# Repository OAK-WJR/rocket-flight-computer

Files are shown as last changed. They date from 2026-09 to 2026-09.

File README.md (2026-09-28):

# Rocket Flight Computer (M3 single board)

Flight computer for an amateur high-power rocket: 2S LiPo, STM32H743VIT6, IMU (ICM-45686), barometer (MS5611), GNSS (SAM-M10Q), QSPI flight log, USB and a RunCam camera interface. The goal is **one 46 mm-wide, four-layer board that fits a 54.66 mm ID airframe**, including dual pyro channels and four-servo roll control.

> **Current status: M3-ASSY-R2 is the complete-function CAD candidate, not flight hardware.** Power / MCU / sensors / logging / USB / GNSS / camera **plus** the actuator switch, four servos, two independently fused pyro channels with a complete arming break, pull-pin and buzzer are routed on one 46 × 238 mm four-layer board. DRC, ERC and schematic parity are zero, every part was checked against its datasheet ([docs/R2_VERIFICATION.md](docs/R2_VERIFICATION.md)) and the actuator band is simulated ([m3_design/sim_r2](m3_design/sim_r2/FINDINGS.md)). Nothing has been built or measured, and R2 firmware does not exist yet. Full requirements and gaps: [STATUS.md](STATUS.md).

## Layout

| Path | Contents |
|---|---|
| `m3_design/assembly_review/` | **The current KiCad project (the single source of truth)**: `m3.kicad_pro`, fourteen schematic sheets, PCB, project-local footprints, symbols and 3D models, and the review notes `ASSEMBLY_REVIEW.md` |
| `m3_design/sim_r2/` | ngspice suite for the R2 actuator band (`run.py`, `RESULTS.md`, `FINDINGS.md`) |
| `reference/` | `m1_power_actuator/`: the legacy M1 actuator board R2 was merged from; `m3_assy_r1/`: the R1 board the v0.8.1 firmware and `diagnostics/` are still bound to |
| `docs/` | Ordering guide (`ORDERING.md`), verification record (`R2_VERIFICATION.md`), actuator merge record (`M3_ACTUATOR_MERGE.md`), design rationale: frozen design and BOM, circuit review, FMEA, margin prescription, airframe geometry, automated test design, simulation, design history |
| `m3_firmware/` | Bench diagnostic firmware v0.8.1 source, binding / protocol definitions and tests; `build_assembly_*/` holds prebuilt images **for R1 only — do not run them on R2** |
| `diagnostics/` | Host-side diagnostic and fault-localisation tools (USB, SWD, log recovery, test-point map) |
| `quality_audit/` | Board-level audit: metadata conflicts, 3D model paths, DRC / ERC evidence |
| `tools/check.sh` | One-command board gate |

## Quick start

Requires **KiCad 10.0.x** (file format 20260206; older versions cannot open it) and Python 3.9+.

```bash
tools/check.sh                                     # DRC + ERC + parity + metadata/3D audit; passes only at zero
python3 m3_design/check_actuators.py               # pyro / arming / servo safety contract
python3 m3_design/sim_r2/run.py                    # SPICE suite (needs ngspice)
open m3_design/assembly_review/m3.kicad_pro        # open in KiCad
pip install -r diagnostics/requirements-lock.txt   # host diagnostic dependencies (pyocd etc.)
python3 -m unittest discover -s diagnostics -t . -p 'test_*.py'
(cd m3_firmware && PYTHONPATH=.. python3 -m unittest test_firmware test_gnss test_usb)
```

Building the firmware needs the ARM GNU Toolchain 15.2.rel1 unpacked into `m3_firmware/toolchain/` (see the `TOOL` path at the top of `m3_firmware/build.py`). **After any PCB change, `build.py` refuses to build until the pin binding has been reviewed again** — this is intentional.

## Collaboration

See [AGENTS.md](AGENTS.md): development rules, safety constraints, what remains for the complete PCB, and the contribution workflow.

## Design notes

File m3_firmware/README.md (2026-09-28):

# M3 bench diagnostic firmware

> **M3-ASSY-R2 (actuator merge, 2026-09-25): no firmware exists for R2 yet.** R2 moves LED_RED from PE3 to PE8 and turns PE3 / PE6 into no-net sentinels beside the pyro gates PE4 / PE5, so **v0.8.1 must not be run on an R2 board** (it drives PE3). `build.py` already refuses to build against the changed PCB hash; the reviewed R2 GPIO roles are in [`pins_r2.json`](pins_r2.json) and the rules in [`../docs/M3_ACTUATOR_MERGE.md`](../docs/M3_ACTUATOR_MERGE.md). A new binding must be written from `assembly_binding.py` together with the first R2 firmware, not by editing the R1 hash. The R2 hardware also relies on two firmware rules (`docs/M3_ACTUATOR_MERGE.md` §2.6): every pyro fire pulse ends after 20 ms, and flight state survives an MCU reset so channel 2 still fires. Full list: `docs/R2_VERIFICATION.md` §5 (includes reading VLOGIC_SENSE / V3V3_SENSE on ADC3 and keeping U3 a W25Q128JV-IQ).

**Current version: v0.8.1 for M3-ASSY-R1.** Usage: [ASSEMBLY_DIAGNOSTICS.md](ASSEMBLY_DIAGNOSTICS.md). The host-side [triage entry point](../diagnostics/TRIAGE.md) ties USB snapshots, fault history and independent instrument readings to the current PCB's test points, keeping disconnections and partial evidence. **Nothing has been verified on a real board, and the complete M3 is not finished** (see [../STATUS.md](../STATUS.md)).

This is bench firmware: it acquires and logs diagnostic data and exposes it over SWD and USB. It contains **no flight-state estimation, attitude control, servo or pyro actuation**.

## What it does

| Subsystem | Implementation | Scope of the check |
|---|---|---|
| MCU start / liveness | ST startup code, HSI system clock, a heartbeat published every second | Reading back two records with consistent version / UID shows the program is running |
| Y1 crystal | Keeps running on HSI; enables the HSE briefly and records HSERDY; USB uses HSE → PLL3 48 MHz | Ready bits only; frequency, drive margin and drift are not measured |
| U4 IMU | ICM-45686 over SPI1: identity, raw accel / gyro / temperature at most once per second | See [IMU_DIAGNOSTICS.md](IMU_DIAGNOSTICS.md) |
| Rail voltages | ADC3: PC2_C / PC3_C dividers and VREFINT | Raw codes, reference calibration, VDDA / VLOGIC / 3V3; not yet compared with a meter. See [ACQUISITION.md](ACQUISITION.md) |
| U5 barometer | PROM / CRC at power-up; D1/D2 at OSR4096 with second-order compensation | Raw 24-bit codes, coefficients, Pa / 0.01 °C; accuracy not proven |
| U3 flash | Identity; append-only diagnostic log with single / quad-line write verification | See [STORAGE_DIAGNOSTICS.md](STORAGE_DIAGNOSTICS.md) |
| USB | TinyUSB 0.21.0 CDC: snapshot and read-only log download | See [USB_DIAGNOSTICS.md](USB_DIAGNOSTICS.md) |
| GNSS | USART6 read-only MON-VER / NAV-PVT polling, raw bytes and freshness | See [GNSS_DIAGNOSTICS.md](GNSS_DIAGNOSTICS.md) |
| Camera UART | One optional device-information query | See [UART_DIAGNOSTICS.md](UART_DIAGNOSTICS.md) |
| Power status | Battery / USB / camera FAULT and source-select ST inputs with history | See [POWER_STATUS_DIAGNOSTICS.md](POWER_STATUS_DIAGNOSTICS.md) |

The four prebuilt images for the current board are in `build_assembly_{inspect,inspect_query,record,record_query}/` (`.bin`, `.hex`, `.elf`, `manifest.json`, `binding.json`). The other `build*/` directories hold only the manifests of historical versions, used by the host tools' compatibility tests.

## Building

Uses the Arm GNU Toolchain 15.2.Rel1 and the ST CubeH7 v1.13.0 HAL/CMSIS. The vendor files in `vendor/` are pinned to fixed Git commits and verified by Git blob and SHA-256 at build time, with their licences kept; `fetch_vendor.py` can restore them from the official public repositories without any API key.

Get the toolchain from the [official Arm guide](https://learn.arm.com/install-guides/gcc/arm-gnu/) and unpack it into `m3_firmware/toolchain/` so that `TOOL` at the top of `build.py` resolves (`toolchain/arm-gnu-toolchain-15.2.rel1-darwin-arm64-arm-none-eabi/bin/`); on other hosts, adjust that path. Then:

```sh
python3 m3_firmware/build.py --board assembly --imu-samples --storage inspect
python3 m3_firmware/build.py --board assembly --imu-samples --storage record
# add --camera-query for the camera-query variants
```

The build checks the PCB hash and the native netlist against the firmware pin map, and refuses to build if the board has changed without a reviewed binding. It never touches a probe.

## Reading back a real board

Install the firmware separately with an ordinary debug tool and start from reset / power-up. J2 is wired by signal name: 1 = GND, 2 = SWCLK, 3 = SWDIO, 4 = NRST, 5 = 3V3 reference, 6 = BOOT0 — not the standard Arm 6-pin header. The readback tools never supply power, flash, halt, reset or erase.

Over USB (preferred), with a new output path each time:

```sh
diagnostics/.venv/bin/python -m diagnostics.usb capture \
  --port /dev/cu.YOUR_DEVICE --assembly BOARD_001 \
  --manifest m3_firmware/build_assembly_inspect/manifest.json \
  --out diagnostics/runs/board001_assembly.json
```

Over SWD:

```sh
diagnostics/.venv/bin/python -m diagnostics probes
diagnostics/.venv/bin/python -m diagnostics.mailbox capture \
  --probe-id EXACT_ID --assembly-id BOARD_001 \
  --binding m3_firmware/build_assembly_inspect/binding.json \
  --manifest m3_firmware/build_assembly_inspect/manifest.json \
  --samples 10 --interval 1.2 \
  --out diagnostics/runs/board001_mailbox
```

`EXACT_ID` must match the full enumerated probe ID. The readback checks sequence numbers, CRC32, version, PCB / firmware hashes and the UID read independently over SWD, taking 2–30 records at least 1.2 s apart to check heartbeats and sample counters. Stalled, old-firmware, corrupt or missing data never counts as a pass; hash / UID association is not anti-counterfeit authentication.

`PASS` applies only to that sub-check. The overall report is always `INCOMPLETE` or `ISSUES_FOUND`; no "board passed" is ever produced. If boot failed early or no firmware is installed, the result area may be empty or stale: check registers and external voltages first rather than declaring a sensor broken.

## Tests

```sh
pip install -r diagnostics/requirements-lock.txt
(cd m3_firmware && PYTHONPATH=.. python3 -m unittest test_firmware test_gnss test_usb test_imu test_storage test_camera test_power_status)
```

The tests compile the real production C functions for the host and drive them with scripted line levels / register models to check commands, error propagation and CRCs. **These are synthetic data, not electrical simulation or measurement.**

## Sources

- [ST CubeH7, pinned commit](https://github.com/STMicroelectronics/STM32CubeH7/tree/5abb9764b32e11a6557b90bf39531528019b5761): startup, LDO, HSI, GPIO/HAL and linker templates; per-file URLs in `vendor_manifest.json`.
- [TE MS5611 B3](https://www.te.com/commerce/DocumentDelivery/DDEController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): power-up reset, 2.8 ms reload, inverted CSB address bit and PROM commands.
- [MEAS AN520](https://www.amsys-sensor.eu/sheets/amsys.fr.an520_e.pdf): CRC low-byte handling and the public test vector giving 0xB.
- [Winbond Rev M](https://www.winbond.com/resource-files/W25Q128JV%20RevM%2012242024%20Plus.pdf): the W25Q128JV-IQ's EF4018 and the 9Fh transaction.
- TDK ICM-45686 DS-000577 Rev 1.0 §10.5 / §17.79: SPI read command and the 0xE9 identity.

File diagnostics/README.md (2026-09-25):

# Host diagnostics

**Current: M3-ASSY-R1 / firmware v0.8.1.** Start with the [unified triage entry point](TRIAGE.md):

```sh
python -m diagnostics.triage capture --port ACTUAL_PORT --assembly BOARD_001 --out NEW_DIRECTORY
```

It saves the raw exchange, fault branches, the 30 test-pad coordinates of the current PCB and an empty instrument template, and still produces a report on disconnection. The default firmware directory is `m3_firmware/build_assembly_inspect`. Nothing has been verified on a real board; the complete M3 is not finished.

Other entry points, each tied to the firmware version whose board binding it matches:

| Module | Purpose | Firmware notes |
|---|---|---|
| `diagnostics.usb capture` / `dump` | Read the 1024-byte status snapshot over USB CDC; download the flash log (inspect images only) | [USB](../m3_firmware/USB_DIAGNOSTICS.md), [GNSS](../m3_firmware/GNSS_DIAGNOSTICS.md), [power status](../m3_firmware/POWER_STATUS_DIAGNOSTICS.md) |
| `diagnostics.storage recover` | Parse a downloaded flash image into records, keeping corruption locations and raw records as JSONL | [Storage](../m3_firmware/STORAGE_DIAGNOSTICS.md) |
| `diagnostics.mailbox capture` | Read the firmware's fixed SRAM result area over SWD | [Firmware README](../m3_firmware/README.md) |
| `diagnostics capture` / `report` / `bench-template` | SWD register capture, raw evidence and interpretation of external DC measurements | Below |

The host never flashes, erases or writes target memory. Errors, no fix, stale data and unknown identities are reported separately; a receiver's self-reported accuracy is never treated as a measurement. `examples/` contains synthetic data only.

## SWD register capture

Run from the project root. Offline reports need only Python 3.9+; connecting a probe needs the pinned pyOCD.

```sh
python3 -m venv diagnostics/.venv
diagnostics/.venv/bin/python -m pip install -r diagnostics/requirements-lock.txt
diagnostics/.venv/bin/python -m diagnostics probes
diagnostics/.venv/bin/python -m diagnostics capture --probe-id EXACT_ID --assembly-id BOARD_001 --out diagnostics/runs/board001_first
```

`EXACT_ID` comes from the `probes` output and must match exactly; the first probe is never chosen by default. Use a new output directory every time. A capture stores each address, width, raw value or specific error, sample time, probe / driver version, assembly ID and the board file's SHA-256. Existing records are never overwritten; a driver call taking over 25 s is aborted with partial data kept. This recovers forensic data; it does not recover failed hardware.

J2 is not the standard Arm 6-pin header. Connect the probe by **signal name**:

| PCB J2 | Signal | Use |
|---|---|---|
| 1 | GND | Probe ground |
| 2 | SWCLK | Debug clock |
| 3 | SWDIO | Debug data |
| 4 | NRST | Not actively reset by this tool; may be left unconnected |
| 5 | 3V3 | Probe voltage reference, not a second supply input |
| 6 | BOOT0 | Not used by this tool; never connect it to reset or power |

This stage is for a bare board on a current-limited bench supply; attaching a debugger can change timing / low-power behaviour, so a debug session cannot prove reliability without the probe.

## Interpreting the output

- `snapshot.json` is the raw evidence, `analysis/report.md` gives findings and the next test point, `report.json` is for automated analysis.
- `PASS` applies only to the stated sub-check (e.g. "capacity register reads 2048 KiB"); it does not mean the flash reads and writes, or that the board passed.
- `INFO` is an observation or consistent with the model, `WARNING` needs further observation, `FAIL` clearly breaks that item's criterion, and `NOT_TESTED` / `INCONCLUSIVE` never count as a pass.
- The overall result is always `INCOMPLETE` or `ISSUES_FOUND`; `hardware_qualified` and `fabrication_release` are always false. Exit code 0 only means the capture/report command ran; 2 means the report found a FAIL; 3 means a capture, input or tool error.
- DEV_ID = 0x450 cannot distinguish every orderable part in the family, nor genuine from counterfeit chips / packages. CPUID decoding keeps variant/revision so a normal silicon revision is not misreported as the wrong chip.
- RCC_RSR holds history flags that may accumulate or be cleared by firmware, so no single "reset cause" is forced. With the HSE not enabled, the crystal is not judged broken; a changing clock configuration is reported as a non-atomic snapshot.
- Register capture never runs ADC, SPI, I2C or external QSPI transactions; sensor identity / samples, storage read/write, USB enumeration and real watchdog resets are not tested by it.

## External instrument measurements

```sh
python3 -m diagnostics bench-template diagnostics/runs/board001_first/snapshot.json --out diagnostics/runs/board001_first/bench.json
python3 -m diagnostics report diagnostics/runs/board001_first/snapshot.json --bench diagnostics/runs/board001_first/bench.json --out diagnostics/runs/board001_first/with_meter
```

The template contains the real pads and coordinates, with measurement fields initially null. Fill each real measurement in this structure (the values are only a format example and must never be copied as an acceptance record):

```json
{"value": 3.30, "unit": "V", "uncertainty_v": 0.01, "input_ohm": 10000000,
 "instrument": "actual instrument model / ID", "measured_at": "actual ISO date-time"}
```

`uncertainty_v` is an absolute error bound from the instrument specification, resolution and method; never enter 0 because it wasn't calibrated. Divider checks include 1 % resistors and the meter's input impedance loading the lower arm; the model has no dynamic ADC load. Paired voltages should be measured in the same stable supply configuration. The board file hash, assembly ID and capture_id must agree; this is provenance linking, **not an anti-counterfeit signature, and it cannot prove the physical board matches the PCB file**.

On a severe power-tree drop, check the USB / battery input path, then the U2/L1 regulator stage or the L2 sensor supply branch. Unknown versions never get guessed reference designators. The report keeps candidate causes such as "upstream open / downstream short" and never declares a chip broken from one voltage. 3.3 V ± 5 % is only a screening window.

## Connection behaviour and basis

pyOCD's normal connect, auto-unlock and disconnect can halt, erase or resume the core, so this tool does not use normal target initialisation ([pyOCD session options](https://pyocd.io/docs/options.html)). It is pinned to pyOCD 0.45.1: a session in an empty temporary directory with no configuration or user scripts; after `open(init_board=False)` it connects only the DP and AP0 and reads a whitelist through `MinimalMemAP`; a guard proxy only allows writes to the AP's CSW and to TAR for listed addresses, rejecting DRW/BD data writes. It never calls target.init, reset, halt, resume, unlock or flash algorithms, never reads the flash program area and never touches GPIO. **The SWD protocol itself must write debug-port configuration / addresses and request debug power; this is not a zero-disturbance measurement.** ([pyOCD API examples](https://pyocd.io/docs/api_examples.html), [H743 target source](https://github.com/pyocd/pyOCD/blob/v0.45.1/pyocd/target/builtin/target_STM32H743xx.py))

Register addresses / bit definitions come from the pinned [ST CMSIS H743 header](https://github.com/STMicroelectronics/cmsis-device-h7/blob/81db1ec63cdc191fae1565b772da3ea5aa29a683/Include/stm32h743xx.h) and [Arm CMSIS](https://github.com/ARM-software/CMSIS_6); `sources/manifest.json` keeps the exact URLs and SHA-256, with the original headers and licences.

## Regression tests

```sh
python3 -m unittest discover -s diagnostics -t . -p 'test_*.py'
```

The tests cover stopping chip-specific reads after a wrong family, capacity mismatches, chip revisions, timeouts / missing evidence, reset history, clock changes, fault-address VALID bits, L2 branch drops, swapped divider arms, meter loading, error bounds, wrong board / session / duplicate JSON data, and a real pyOCD MinimalMemAP rejecting memory writes through the guard proxy. API tests are not circuit simulation or a real-board connection.

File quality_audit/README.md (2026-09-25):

# Manufacturing-file consistency audit

Tools that check a KiCad board for problems DRC does not catch, and bind the evidence to the exact input files.

| Script | What it checks |
|---|---|
| `audit_artifacts.py` | Conflicting distributor part-number fields on the same part (e.g. `LCSC` vs `LCSC Part`), missing or unresolved 3D model paths, absolute (non-portable) model paths, footprints without a courtyard |
| `normalize_metadata.py` | Reads a board's part table and reports drift against a generator's intended part table |
| `verify_board.py` | Fresh read-only DRC (all severities + schematic parity) and ERC with SHA-256 hashes of every input (board, schematic sheets, libraries, models); exits non-zero on any unresolved finding |
| `sexpr.py` | Minimal KiCad s-expression reader shared by the scripts |

Usage (also wrapped by `tools/check.sh`):

```sh
python3 quality_audit/verify_board.py m3_design/assembly_review/m3.kicad_pcb --output /tmp/audit.json
python3 -m unittest quality_audit.test_quality_tools
```

A zero exit status covers only the checks listed; it says nothing about electrical, mechanical or flight readiness.

History: the first audit (2026-09-07) of the legacy two-board design found 60 components carrying two contradictory LCSC numbers (footprints imported from EasyEDA carried a baked-in example part number), absolute 3D model paths, and build scripts that hid upstream failures. Those were fixed in the M3 libraries; the current M3-ASSY-R1 board passes this audit with no findings.

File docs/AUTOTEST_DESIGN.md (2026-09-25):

> 2026-09-07 implementation status: limited SWD register capture and interpretation of external DC measurements are implemented; see [diagnostics/README.md](../diagnostics/README.md). The rest of this document is the older M1/M2 test design and has not been executed. The current implementation does not treat a fixed CPUID, the reset flags or a single voltage reading as proof of an exact chip or a unique fault; sensor, storage, watchdog and actuator functional tests are not complete. Full M3 status: [STATUS.md](../STATUS.md).

# AI-driven automated fault localisation — design (TEST-1, 2026-09-03)

> This is not excerpted from another report; it was designed new for requirement 3 (automated fault localisation), expressed in the same change schema so it can be merged with the four other lists.
> Baseline: 101 soldered parts / 39 part numbers / 78 nets / 370 connections. Net addition in this document: **5 parts, 0 new part numbers, 2 GPIOs** (FMEA H-1's +3 parts / +1 part number is also adopted but belongs to H-1; do not double-count when merging).

---

## 0. One-sentence conclusion

**Today the board's visibility into its own power chain is: RAW visible, 3V3A visible (for free), everything else blind.** Add **two dividers (5 parts, 0 new part numbers, two free ADC pins PC2/PC3)** plus FMEA's already-proposed H-1, and the whole chain `BAT+ → load switch → RAW → diode OR → buck → LC → sensor rail` has a digital reading at every stage boundary; together with **a RAM-resident self-test program loaded over SWD that does not depend on the flight firmware**, an AI agent can plug in a probe and say within 90 seconds "which stage is broken, what it reads, and what the criterion is".

---

## 1. What the board cannot see today (node by node)

The power chain and every diagnosis-relevant node, checked against the as-drawn netlist and frozen §3.

| Node | Visible today? | Means | Consequence of the blind spot |
|---|---|---|---|
| **BAT+** (upstream of the switch) | ❌ Blind | — | "Battery flat / reed switch not closed / cold joint on J1's SW pin / Q1-Q2 dead" cannot be told apart. The J1 SW cold joint is the killer named in DESIGN_ASSURANCE Tier 2 item 5: perfect continuity on the bench (only 76 µA, no self-heating, no voltage drop), pulled open by vibration = whole-board power loss |
| **FET_S** (common source) | ❌ Blind | — | Cannot tell which of the back-to-back pair is not conducting (but RAW would be 0, merging with the row above) |
| **RAW** | ✅ | `R3/R4` 100k/47k → PC4 (ADC12_INP4) | Existing. 8.4 V → 2.686 V |
| **VLOGIC** | ❌ Blind | — | **The most expensive blind spot**: `D2 (SS34, RAW → VLOGIC)` is the **only** path from the battery to the logic rail. On the bench USB is always plugged in, so with D2 cold-soldered/open everything looks fine; the moment USB is unplugged (i.e. the moment it goes into the rocket) the board dies. No test today can find it |
| **3V3** | ❌ Blind | — | Indistinguishable from 3V3A: with VDDA = 1.8 V, "buck output at 1.8 V" and "L2 cracked, 3V3 fine" give the same reading, and the H743 **still runs** at VDD = 1.8 V, so both faults look like "MCU alive, all sensors dead" |
| **3V3A / VDDA** | ✅ **zero parts** | Solve from VREFINT against `VREFIN_CAL (0x1FF1E860)` | See §1.1 |
| **MCU pin 6 (VBAT)** | ✅ zero parts | Internal ADC `VBAT/4` channel (set `ADC3_CCR.VBATEN`) | Reads near zero if the pin is open. The **only** way to verify that joint without poking a probe onto 0.5 mm pitch |
| **Die temperature** | ✅ zero parts | Internal `VSENSE` + `TS_CAL1/2` | Used for the three-temperature cross-check |
| **PYRO_BUS / ARM state** | ✅ | `R14/R15` → PC5 | Existing |
| **Both pyro drains** | ⚠️ Half blind | `R18/R19`, `R22/R23` → PC0/PC1 | Sees only the drain potential: **the gate chain (470R, 1k, gate bond, FET body, MCU pin configuration) is 100 % uncovered**, so a dead channel is certified healthy by the self-test (DESIGN_ASSURANCE Tier 2 item 8). And with the ARM plug out, healthy FET / shorted FET / open igniter / no igniter **all read 0 V** (FMEA I-1) |
| **Servo outputs (after the 220R)** | ❌ Blind | — | See §3.3; ruled an **accepted blind spot** |
| **Buzzer branch** | ❌ Blind | — | See T-16 in §5; measured indirectly through a 3V3 load step |
| **Both LEDs** | ❌ Blind | — | Not electrically testable; accepted |
| **Pull-pin** | ✅ digital | PD14 | Open = "pulled = permitted", failing toward armed. Compensated by a firmware latch (ruled in DESIGN_ASSURANCE) |
| **VBUS** | ✅ digital | PD15 (only really usable with FMEA H-4's 100k pull-down) | Before H-4 the pin is a floating CMOS input and its reading is meaningless |

### 1.1 What VREFINT does and doesn't prove

Frozen §3.1 ties pin 20 (VREF+) directly to pin 21 (VDDA), both fed from **3V3A**. So `VDDA = VREF+ = 3V3A`, and since VREFINT is converted relative to VREF+ → `VDDA = 3.3 V × VREFIN_CAL / VREFINT_raw`. **Zero parts, zero pins, zero area.**

- **Proves**: the absolute value of 3V3A, to about ±0.5 % (dominated by the factory accuracy of VREFIN_CAL). It therefore also shows the buck is broadly regulating (only 30 mA × 78 mΩ ≈ 2.3 mV across L2, so normally 3V3A ≡ 3V3). It is the **only free detector** for FMEA V-4 (L2 open — a 3 mm wirewound inductor in single string ahead of every sensor and the whole ADC scale); FMEA F-12 already made it a rule, merged here rather than duplicated.
- **Does not prove**: (a) 3V3 itself — once L2 degrades (not open, but a 20–100 Ω cracked joint), VDDA sags to 1.8 V while the buck output is still 3.30 V, and VREFINT reports "3V3A low" without saying which stage; (b) **it fails itself when L2 is fully open** — with VDDA ≈ 0 the ADC does not work at all and readings are meaningless. So VREFINT's output must first pass a plausibility gate (raw code not 0, not full scale, VDDA ∈ 2.0–3.8 V); outside it, report `ANALOG_SUBSYSTEM_DEAD` rather than a voltage.
- **Every other ADC channel's absolute scale is parasitic on it**: with VDDA wrong, PC0/PC1/PC4/PC5 are all wrong **yet mutually consistent** (FMEA V-4's own words). So every criterion in this design is written as a **ratio** or a **VREFINT-calibrated voltage**, never an absolute millivolt window (the same discipline as FMEA §6.3 item 4's `ARM_SENSE / (VBAT_SENSE × 147/47) = 1/11 ± 15 %`).

---

## 2. Minimum sensing set (+5 parts, 0 new part numbers)

Pin choice: CIRCUIT_REVIEW §6 checked all 55 used LQFP100 pins against ST's machine-readable pin data (STM32_open_pin_data / STM32H743VITx.xml) and confirmed along the way that **pins 17/18 = PC2_C/PC3_C are unused in this design**. They are in none of frozen §3.10's reserved/avoid tables, and not in the H743 bootloader pin set of AN2606 Table 113 (the bootloader uses PA9/PA10, PA2/PA3, PB10/PB11, PB6/PB9, PA8/PC9, PA4–PA7, PA15/PB3–PB5, PE11–PE14, PD0/PD1, PA11/PA12). They sit right next to VSSA/VREF+/VDDA (19/20/21), the best analog corner on the board.

> **Mandatory firmware note**: on LQFP100 these two pads are merged `_C` pads. The `PC2SO/PC3SO` bits of `SYSCFG_PMCR` reset to 0 = analog switch closed = the pin is ordinary PC2/PC3 (GPIO + ADC12). **No initialisation code may set these two bits**, or both rail senses silently fail. This must go into the specification — it is exactly the trap "someone copies an H7 template in future" will fall into.

### 2.1 AT-1 · VLOGIC sense → PC2 (pin 17, ADC12_INP12) — +3 parts

`VLOGIC ──R-VL1 (100k)──┬── PC2 ;  ┴ R-VL2 (10k) to GND ;  ┴ C-VL (10 nF) to GND`

| Condition | VLOGIC | PC2 node (÷11) | 16-bit code @ VDDA = 3.3 |
|---|---|---|---|
| USB only (VBUS 5.00, D3 Vf 0.32 @ 120 mA) | 4.68 V | **425.5 mV** | 8452 |
| USB only, worst (VBUS 4.75) | 4.43 V | 402.7 mV | 7999 |
| Battery full (8.4 V, D2 Vf 0.33 @ 150 mA) | 8.07 V | **733.6 mV** | 14571 |
| Battery at LVC (6.0 V) | 5.67 V | 515.5 mV | 10239 |
| TVS clamp transient (BAT+ 19.9 V) | 19.55 V | **1777 mV** | — |

- **The 1/11 ratio rather than 47/147 is deliberate**: 1/11 keeps the worst TVS clamp transient at 1.78 V, safely inside the 4.0 V hard limit PC2 would have if it is TT_a class (the existing `VBAT_SENSE` uses 100k/47k and would put 6.36 V on PC4 in the same event — an existing exposure none of the four reports mentioned; this document simply doesn't copy it). And 100k and 10k are both existing part numbers (C25741 / C25744): **0 new part numbers**.
- **Quiescent current** 73 µA @ 8.07 V / 43 µA on USB. **The node is after the load switch and the diode OR, so it is 0 V with the board off** → zero battery drain in storage, and no path for "external voltage forward-injecting into an ADC pin while VDD = 0", which the frozen document explicitly forbids.
- **The 10 nF is required**: with the 9.09 kΩ source it forms a 1.75 kHz pole, giving ~56 dB rejection of the AP63203's 1.1 MHz input ripple and suppressing coupling from the 12 A servo bus onto RAW/VLOGIC. This channel only needs DC accuracy, not transient bandwidth.

**What it buys** (by value):
1. **D2 open / cold joint — a single-point fatal fault that is completely untestable today.** With battery + switch closed and USB unplugged, `V_RAW − V_VLOGIC` must fall within 0.25–0.45 V (the SS34's forward drop at 100–200 mA). ≈ 0 = D2 shorted; V_VLOGIC ≈ 0 with RAW normal = **D2 open: this board dies the moment USB is unplugged**.
2. **D2 shorted / USB back-feeding RAW.** On USB power alone PC4 must read ≤ 0.15 V (DESIGN_ASSURANCE correction (f) showed D2 is then reverse-biased and RAW near 0). If PC4 reads ~1.49 V, a shorted D2 is putting USB's 5 V onto **the servo header and the ARM terminal** — a safety-relevant fault that today only a person with a meter can find.
3. Buck input headroom and supply-source identification (USB / battery / both) — the denominator for every rail criterion after T-14.

### 2.2 AT-2 · 3V3 sense → PC3 (pin 18, ADC12_INP13) — +2 parts

`3V3 ──R-33A (10k)──┬── PC3 ;  ┴ R-33B (10k) to GND` (**no capacitor**, reason below)

- Node **1.650 V** nominal, **165 µA** quiescent (only while the board is powered), 5.0 kΩ source impedance. Both C25744, 0 new part numbers.
- Worst case: a high-side buck short making 3V3 = 8 V puts 4.0 V on the node — but then VDD = 8 V and the MCU is already dead, so sizing the ratio for that case is pointless. In normal operation and every survivable fault the node is ≤ 1.80 V.
- **The key criterion is a ratio, not a voltage**: `k = V_3V3 / V_VDDA`. Normally **k = 1.000** (2.3 mV across L2).
  - k high (> 1.05) → **the L2 / 3V3A stage**: a cracked inductor joint, a local short on the sensor rail. A 50 Ω crack gives k = 1.83.
  - k normal but both low → **the buck stage** (AP63203, L1, Cout, VLOGIC input).
  - Exactly the pair of faults that is indistinguishable today, separated with two 0402s.
- **Deliberately no capacitor**: T-16 (buzzer load step) measures the **transient dip** of 3V3 under a 95 mA step (about 40 mV deep, recovering in hundreds of microseconds), and a 10 nF would smear it out. A 5 kΩ source needs under 0.4 µs of 16-bit ADC sampling time, so it can run at ~1 MSPS and capture the transient directly. "Each node's filtering is set by the quantity it has to measure", not copied.

### 2.3 AT-3 · The zero-part pieces (internal channels + per-board calibration)

- Enable all three internal channels VREFINT / VBAT4 / VSENSE and log them (merged with FMEA F-12).
- **Per-board divider calibration**: 1 % resistors give ±1.4 % uncertainty in divider ratio, while D2's drop is only 0.35 V — uncalibrated, §2.1 item 1 can only catch gross faults like "open", not "degraded". Method: after assembly, apply a known 8.000 V to the BAT terminal from a bench supply (its own display is the reference), record the PC4/PC2 codes, and write them with the VREFINT-calibrated 3V3 divider ratio into the configuration block. **5 minutes per board, once, zero parts**; criteria then tighten from ±1.4 % to ±0.2 %, and the `V_RAW − V_VLOGIC` window from ±0.16 V to ±0.03 V. An uncalibrated board may still run, but the corresponding checks are downgraded to `DEGRADED (uncalibrated)` in the report.

### 2.4 Three "do not add"s stated once

- **No BAT+ divider.** Any divider measuring the battery upstream of the switch is a **permanently live** path; with the board off VDD = 0 while that node sits at 2.7 V, forward-injecting about 77 µA through the ADC pin's ESD structure into the unpowered VDD rail and holding the MCU in an undefined half-powered state — exactly the class of path the frozen document closed when it stopped taking the pyro bus from raw BAT, and a violation of the FT pins' own "no positive injection at all" rule. **The cost, stated plainly**: with the switch open, the battery is invisible to firmware. **The free substitute**: with the switch closed PC4 reads the battery voltage, so the only remaining blind spot is the single "switch open" state, where a two-state test is possible (see T-15), and the residual four-way choice {battery / reed switch / J1 joint / Q1-Q2} is closed by the instrument-free action "swap in a known-good battery pack".
- **No 3V3 current sensing.** See §3.
- **No servo output readback.** See §3.3.

---

## 3. Is current sensing worth it? (a conclusion, not options)

**Conclusion: no.** No shunt and no INA-class current-sense amplifier on the 3V3 rail. Three reasons, any one sufficient:

1. **It puts two new solder joints in series with the MCU's only supply path.** That was the core reason the frozen document deleted the 0 Ω sense jumper, and DESIGN_ASSURANCE re-checked and reinforced it ("adding links to a single-point-failure chain"). Requirement 2 asks for **independent protection layers**, not more links in the critical path.
2. **The only extra fault it catches is bounded.** Correct voltage with abnormal current can only be "a partially shorted decoupling capacitor": the rail stays in spec and the board still works; the consequence is heat and endurance, not mission failure. A short that really kills the mission always pulls the rail down, which is visible as voltage.
3. **A better zero-part substitute already exists, measuring a more useful quantity**: **use the buzzer as a calibrated 95 mA step load and measure 3V3's transient dip and recovery time on PC3** (T-16). In one go it gives the buck's load-transient response, whether the output capacitors are present, whether the inductor saturates, and whether the buzzer branch itself conducts — none of which one steady-state current number provides.

**Companion procedure item (0 parts)**: DESIGN_ASSURANCE already mandates "first power-up is always USB first, then a current-limited bench supply", and that supply's own ammeter is the absolute reading. Give it a numeric criterion in the procedure: **at 200 MHz / VOS3 idle with all sensors on and GPS locked, the 3V3 branch draws 128–184 mA; the whole board (VLOGIC side) draws 75–120 mA at 8.4 V**; outside that, stop. This turns "current" from a permanent board-level liability into a one-time assembly acceptance reading.

---

## 4. Links: how the AI actually connects

### 4.1 Primary link = SWD (ST-LINK / CMSIS-DAP + pyOCD or OpenOCD)

**It is the primary link because it needs no cooperation from the flight firmware.** The probe can halt the core, read and write any memory, program flash, and — the core technique of this design — **load a RAM-resident self-test program (AT-7) into AXI SRAM and run it directly**. The whole test suite therefore **does not depend on whether the firmware under test exists, is correct, or has hung**. That is the only form that works for "an agent plugs into a freshly soldered board".

- The 1×6 header J2 already exists, and DESIGN_ASSURANCE has ruled it **must be fitted, never DNP**; this document adds one more reason: it is the main test port.
- Automation: the Python API or CLI of `pyocd`/`openocd`, fully scriptable, zero manual steps. SEGGER RTT drains a RAM ring buffer over SWD for a bidirectional console with **zero pins and zero parts** (SWO cannot be brought out — PB3 is SPI1_SCK, settled in DESIGN_ASSURANCE §4.6).
- **Can diagnose**: power rails (through ADC registers), the core, the clock tree (RCC registers), every bus and device, flash, the pyro chain, the watchdog, reset causes.
- **Cannot diagnose**: the USB peripheral itself, the USB-C connector and D+/D− routing, and "the firmware's autonomous behaviour without a probe attached".
- **Needs a $10–20 probe** — the only barrier.

### 4.2 Backup link = USB CDC

- **It is only available once a lot already works**: the MCU running, HSE correct, PLL locked, USB PHY and connector intact, firmware running far enough to enumerate. So it **is not suitable as the primary link** — it carries the least diagnostic information exactly when you need diagnosis most.
- **Its irreplaceable value**: (a) it is the **only** thing that verifies the USB path itself; (b) it is the download path for the 16 MB flight log (RTT can do it too, but at 100 kB/s 16 MB takes 160 s); (c) it provides the board's **only ppm-class clock reference** — a USB SOF every 1.000 ms, derived from the host's crystal (see T-22); (d) no probe needed.
- When the firmware is completely dead, the ROM bootloader's DFU uses the same connector. **Note the conflict with DESIGN_ASSURANCE's J2 reorder**: after the reorder a 2.54 mm jumper physically cannot select DFU, so entering DFU needs a fly wire or tweezers. With SWD available that cost is acceptable, but it must be recorded.

### 4.3 The installed reality (GEOMETRY_REV_G)

- `GEOMETRY_REV_G §3.4`: USB-C is on the starboard long edge with only **3.80 mm** of radial room at the board edge; the USB plug shell does not fit → **"on-board USB is bench-only; data download / flashing requires pulling the sled"**, already promoted to mechanical rule ④.
- The same document computes, for J2 (x = 41, y 57.0–72.24), a maximum crimp housing of 16.75 mm against 18.633 mm of clearance there, **1.88 mm spare ✓**.
- Ruling: **when installed, J2 is (geometrically) the only possible service port, with only 1.88 mm of margin** → SWD cables must use **fly leads / low-profile right-angle housings**, not standard shielded ribbon housings. **And stated honestly**: the terminals cannot be tightened inside the airframe (§7.2 mechanical rule ③), so any re-termination already means pulling the sled; in practice "testing the complete rocket" = testing with the sled pulled out and the rest of the harness still connected. **No USB pigtail** — that would be a new connector, live in flight and chafing on the airframe wall, doing what an existing port already does.

---

## 5. Test suite (ordered, with numeric criteria; the first failure localises)

Three configurations, loaded in stages. Every item states its `prerequisite` (if not met, it is skipped and marked `SKIPPED(prereq)`), so **the first FAIL is the stage that has been localised**. All criteria use VREFINT-calibrated voltages or ratios.

### CFG-A Bare board + USB, nothing else connected (about 90 s, fully automatic)

| ID | Check | Criterion | FAIL localises to |
|---|---|---|---|
| T-01 | SWD DP IDCODE | Exactly `0x6BA02477` | 3V3 not up / NRST held / SWDIO-SWCLK open or shorted |
| T-02 | CPUID `0xE000ED00` | `0x411FC271` (Cortex-M7 r1p1) | Relabelled or wrong MCU |
| T-03 | DBGMCU_IDC / flash size / UID | Device ID = 0x450; flash size @ `0x1FF1E880` = 2048 KB; UID @ `0x1FF1E800` three words non-zero and not all F | Swapped for an H743VG (1 MB) or H723; UID all F = unreadable |
| T-04 | `RCC_RSR` | PORRSTF expected on first power-up; IWDG1RSTF / low-power reset flags = FAIL | Previous run was abnormal; this is the evidence for "charge didn't go vs computer refused to fire" |
| T-05 | AXI SRAM march (64 KB, 0x5A5A / 0xA5A5 / address patterns) | 0 mismatches | Core / bus / VCAP decoupling (pins 48/73, 2.2 µF each) |
| T-10 | VDDA (VREFINT) | **3.135–3.465 V**; raw code not 0 and not full scale | Low = buck or LC (T-11 separates them); high = buck out of control; out of range = analog subsystem dead (L2 fully open) |
| T-11 | 3V3 (PC3) and ratio k | V = **3.135–3.465 V**; **k = V3V3 / VDDA = 0.95–1.05** (0.99–1.01 calibrated) | k high → **the L2 / 3V3A stage**; k normal with both low → **the buck stage** |
| T-12 | MCU pin 6 (internal VBAT/4) | **0.784–0.866 V** | Pin 6 cold joint (reads near zero) |
| T-13 | Die temperature | **15–60 °C** at cold start | Local short (hot at power-up) |
| T-14a | VLOGIC (PC2), USB only | **4.20–4.85 V** | Low → D3 open / high-resistance, or USB supply collapse |
| T-14b | RAW (PC4), USB only | **≤ 0.15 V** | High (~1.49 V) → **D2 shorted**; USB 5 V is already on the servo header and ARM terminal |
| T-20 | RCC status | HSERDY = 1, PLL1RDY = 1, SWS = PLL1, CSS not triggered | 25 MHz crystal / load capacitors / soldering |
| T-21 | Clock vs IMU | Mean of 8192 DRDY intervals **1250 µs ± 3 %**, jitter σ < 5 µs | Wrong HSE frequency (wrong crystal or wrong CL), or the IMU not on the 800 Hz step (a relabelled 42688 has no 800 Hz step) |
| T-22 | Clock vs USB SOF (when USB is enumerated) | SOF interval **1000.0 µs ± 0.05 %** | The board's only ppm-class clock criterion |
| T-30 | QSPI identity + **quad-line proof** | JEDEC = `EF 40 18`; after setting QE, write 256 B of LFSR to a scratch page in 1-4-4 and read back in 4-4-4 with **0 byte errors** | ID fails → NCS/CLK/IO0/IO1 or VCC; **ID passes but quad fails → PE2 (IO2) or PD13 (IO3) open** (a single-line ID read still returns a perfect EF 40 18 with both open) |
| T-31 | IMU WHO_AM_I | `0xE9` | SPI1 routing / CS / 3V3A |
| T-32 | IMU IREG indirect-register loopback | Written value reads back | Relabelled part (the 42688 has no IREG path) |
| T-33 | **IMU noise floor and liveness** | 2048 samples at rest: \|a\| = **1.000 ± 0.05 g**; per-axis gyro σ ∈ **[0.010, 0.30] °/s**; per-axis accel σ ∈ **[0.5, 8.0] mg**; **≤ 2 identical consecutive samples** | σ = 0 → data path frozen / cracked die / DMA stuck (exactly the case where WHO_AM_I passes while the device is dead); σ too large → cracked joint or dirty supply |
| T-34 | IMU DRDY interrupt count | **780–820 edges** in 1.000 s | PE10 open — and the IWDG's only feed point hangs on it |
| T-35 | MS5611 address probe | Probe 0x76 and 0x77; **exactly one ACKs** | Neither → I2C1 / pull-ups / 3V3A / PS pin |
| T-36 | MS5611 PROM | CRC-4 passes; no 0x0000/0xFFFF in C1..C6, not all six equal | Counterfeit / cracked die / cold joint |
| T-37 | **Barometer noise floor** | 100 samples at rest at OSR4096: σ ∈ **(0.002, 0.020] mbar**; absolute value within ± 40 mbar of the site pressure supplied by the agent | σ ≈ 0 → data frozen; σ > 0.020 → relabelled MS5607 or bad joint |
| T-38 | Three-temperature cross-check | \|T_die − T_baro\| ≤ 15 °C; \|T_imu − T_baro\| ≤ 5 °C | One of them is lying |
| T-39 | GPS UART | Send UBX-MON-VER; a UBX response with a correct checksum within 1.2 s | PC6/PC7 swapped, module supply, dead module. **Open-sky sub-item** (INFO, not FAIL): ≥ 4 satellites with C/N₀ ≥ 35 dB-Hz within 120 s |
| T-3A | I2C1 bus health | With drivers released, SCL and SDA both read high; the 9-clock + STOP bus-recovery sequence completes | Missing 4.7k pull-up or a stuck slave |
| **T-40** | **Pyro gate pull-down integrity (zero parts)** | Configure the gate pin as input with the **internal pull-up** (~40k) and read: must read **0** (the external 1k pull-down holds the node at 0.080 V) | R17/R21 missing, tombstoned or cold-soldered — the only thing holding the pyro gate down at power-up, with no means of observation today short of a meter. **FAIL → the board must refuse to arm** |
| **T-41** | **Pyro cold four-state (needs H-1)** | ARM plug out, both gates low; read PC5/PC0/PC1 together and interpret per the FMEA table (nominal 40.5 / 31.4 / 56.9 mV, scaled down ~6 % after a one-time bench calibration of the BAT54A Vf) | Both < 5 mV → **FET drain-source short or drain shorted to ground → hard stop, refuse everything, do not touch the ARM plug**; any > 100 mV → pull-up network or divider damaged |
| **T-42** | **Pyro active conduction (needs H-1)** | Plug out, no igniters: drive each gate high for 10 ms in turn; that channel's CONT must collapse to **< 8 mV** and recover within 2 ms | No collapse → 470R open / gate bond broken / FET open / MCU pin not driving. **The only way in the whole design to verify the firing path's switching element end to end**; bridgewire current ≈ 70 µA (from the other channel's pull-up), genuinely zero energy |
| T-52 | VBUS detect (needs H-4) | Cable in reads 1 (node 2.50 V); cable out reads 0 within 200 ms | R9 or the H-4 pull-down missing |
| T-60 | Log round trip | Write 4 KB of records, read back with matching CRC32; readback throughput over the chosen link ≥ 50 kB/s | Flash sector / driver / link |
| T-62 | Firmware image CRC32 | Matches the constant written at link time | Interrupted download → refuse to leave DISARMED |

### CFG-B Add battery + external switch (about 30 s, including one manual switch flip)

| ID | Check | Criterion | FAIL localises to |
|---|---|---|---|
| T-15 | RAW two-state | Switch open: **≤ 0.15 V**; switch closed: **6.00–8.45 V** | Still 0 when closed → {battery / reed switch / **J1 SW pin cold joint** / Q1-Q2}; 3.0–5.5 V → one of the back-to-back pair not fully on, or a deeply discharged battery |
| **T-14c** | **D2 check** (USB out, switch closed) | **V_RAW − V_VLOGIC = 0.25–0.45 V** (± 0.03 V calibrated; uncalibrated, widen to 0.05–0.70 and guarantee only open detection) | ≈ 0 → D2 shorted; V_VLOGIC ≈ 0 with RAW normal → **D2 open: this board dies the moment USB is unplugged**. Untestable today |
| T-16 | **Rail load step (buzzer as a calibrated 95 mA load)** | ① first a 200 µs pulse; Δ3V3 must be **< 0.30 V**, otherwise abort immediately; ② then 5 ms DC, capturing the transient on PC3 at ~1 MSPS: dip **15–120 mV**, recovery **< 200 µs**, VDDA never below 3.10 V | Dip **< 3 mV** → buzzer branch open (Q5 / coil / wrong pad pairing) — **a mute buzzer detected without listening**; dip > 250 mV or no recovery → **D6 reversed** (a forward-biased diode from 3V3 to ground), shorted coil, or missing buck output capacitors / saturating inductor |
| T-22′ | Repeat T-10/T-11 on battery power | Same criteria | The buck behaves differently at 8.4 V input than at USB's 5 V |

### CFG-C Full vehicle configuration (about 3 min, with explicit manual steps)

| ID | Check | Criterion | FAIL localises to |
|---|---|---|---|
| T-43 | Arming state | With the ARM plug inserted, `ARM_SENSE / (VBAT_SENSE × 147/47) = 1/11 ± 15 %` | Plug not seated / 5 A fuse blown / R14 open |
| T-44 | Continuity with igniters | Each CONT = `RAW/11 ± 10 %` (0.700–0.830 V at 8.4 V); ~57 mV with no igniter, 13× separation | Open bridgewire / terminal not clamped. **Note**: a "short" clamped onto bare wire is indistinguishable from a good bridgewire (see §6) |
| T-50 | Servo outputs | **Register level only**: TIM5 CCR, GPIO MODER/AFR/ODR as expected | Proves only the MCU side. No electrical coverage on the board side (§3.3) |
| T-51 | Pull-pin | Reads 0 with the pin in; after the agent prompts "pull the pin", a clean 0 → 1 transition within 50 ms with < 3 bounces; the firmware latch requires having seen 0 first | Reads 1 at t = 0 → pin not inserted **or wire broken** (indistinguishable, which is exactly why the latch exists) |
| T-61 | **Watchdog proof** | Deliberately stop feeding; the IWDG must reset within **380–480 ms**, and after reset `RCC_RSR.IWDG1RSTF = 1` | The watchdog was never enabled — the difference between "a watchdog" and "a comment", which almost nobody tests |
| T-64 | Live pulse into a dummy load | Replace the igniter with a 1 Ω dummy load, 20 ms pulse: CONT < 100 mV during the pulse, RAW dip < 1.5 V, pulse width 19–21 ms (policed by the TIM2 hardware timeout) | The only test of the real firing-energy path |
| **T-65** | **Bay venting (zero parts; turns an "untestable" into a testable)** | Close the bay and warm it gently by hand/lamp for 5 min, logging P and T together: **\|dP/dT\| < 0.5 mbar/K** | An unvented sealed bay gives, by the ideal gas law, `P/T = 1013/293 = 3.46 mbar/K`, 7× separation. **FAIL = the bay has no vent or it is blocked**, and apogee detection would follow bay temperature rather than altitude |
| T-66 | Battery / harness resistance trend | Step all four servos together and record the RAW dip; compare with the baseline recorded at build, **warn if it changes > 30 %** | Battery ageing, loose terminals, bad harness crimps. The absolute value is unavailable (no current sensing), the trend is |

---

## 6. What still cannot be tested (the honest list)

| Item | Why it cannot be measured electrically | What covers it |
|---|---|---|
| **Control-loop signs** (gyro Z sign × servo direction × board mounting orientation) | With the board still, feedback is zero; completely silent on the bench. DESIGN_ASSURANCE's number-one killer; all four servos get the same wrong sign | **A mandatory manual step**: in closed loop, roll the airframe by hand; all four fins must deflect to resist, and log "command vs measured" sign. Plus a laminated card and the silkscreened coordinate triad |
| **Servo linkages, fin angles, fin freedom** | The board cannot see the linkages | Manual fin sweep, visually (the same action as above, no extra time) |
| **Servo output channel electrical integrity** (220R open, one SRV05-4 channel dead) | No readback path after the 220R | Unpowered DC signature: each J5A pad reads **10.22 kΩ** to ground (R24 + R28; nothing else on the connector reads that value) + the mandatory manual sweep above. **Ruling: no 5-part readback network for it (§3.3)** |
| **Whether the igniter is really buried in the charge, and whether the charge is damp** | Continuity only proves the bridgewire, not position or powder | Checklist + loading photos |
| **Terminal clamped onto bare wire vs a good bridgewire** | Same order of resistance (CIRCUIT_REVIEW 2.9) | No electrical means. Procedure: ferrules + visual check after termination + torque stripes |
| **Absolute battery internal resistance** | No current sensing, ΔI unknown | T-66's trend criterion (± 30 % of baseline) |
| **Whether the two LEDs light** | Not electrically testable | Eyes; and they are invisible in flight configuration anyway — the buzzer is the status channel in a closed bay, and T-16 covers it electrically |
| **VCAP decoupling (pins 48/73, 2.2 µF each)** | No observation node | Unpowered `VCAP1–VCAP2 = OL` (proves they are separate) + T-05's SRAM march (degradation shows up first as bus errors) |
| **Vibration / heat-soak behaviour in flight** | Does not exist on the bench | DESIGN_ASSURANCE §6.2's tap test and car heat soak, reusing this suite's criteria |

---

## 7. Machine-readable output

**Two layers, the same data, two independent paths.**

**Layer 1 — a RAM result block (most robust, independent of any serial protocol).** The self-test writes its results into a struct at a fixed AXI SRAM address: magic `"RKTP"` + version + monotonic sequence number + an array of check records. The agent **reads memory directly over SWD** to collect it, without needing any serial protocol to work. The sequence number increments after each completed check, so **even if the self-test hangs at some step, the agent knows which step it died on**.

**Layer 2 — streamed line output (RTT or USB CDC), sent as it runs, not buffered.** One line per check:

```
#T-11 3V3_RAIL 3.2910 V [3.1350,3.4650] PASS stage=BUCK
#T-14c D2_DROP 0.0090 V [0.2500,0.4500] FAIL stage=OR_DIODE_D2
```

**Streaming rather than batching is a key criterion**: the most informative failure is the one that hangs and never returns, and only streamed output can pin it to a specific check.

**Final report (JSON, for the agent)**:

```json
{ "schema":"rktfc.selftest/1", "board_uid":"...", "fw_sha":"...", "link":"swd",
  "config":"CFG-B", "utc":"2026-09-03T…", "cal":"calibrated",
  "verdict":"FAIL", "first_fail":"T-14c", "failed_stage":"OR_DIODE_D2",
  "checks":[ {"id":"T-11","name":"3V3_RAIL","stage":"BUCK","prereq":["T-10"],
              "value":3.2910,"unit":"V","band":[3.135,3.465],"verdict":"PASS",
              "raw":{"adc_code":32690,"vdda":3.3012},
              "localises":"AP63203 / L1 / Cout"} , … ] }
```

Three rules:
1. **Every check carries a `stage`** (a physical stage: `LOAD_SWITCH` / `OR_DIODE_D2` / `BUCK` / `LC_3V3A` / `SPI1` / `PYRO_CH1_GATE` …) — the agent wants "which stage is broken", not the check's name.
2. **Every check carries `raw`** (raw ADC codes, VDDA, register values), so the agent can recompute rather than trust the firmware's conversion.
3. **The same JSON is written into the flight log header as record type `0x02`**, right after DESIGN_ASSURANCE's `0x01` header. When downloading the log from a board that came back in pieces, the first thing visible is "how the board saw itself before launch".

---

## 8. Net impact

| Item | Count |
|---|---|
| New soldered parts | **+5** (100k × 1, 10k × 3, 10 nF × 1) → 101 → 106 (+4.95 %) |
| New part numbers | **0** |
| GPIOs used | **2** (PC2 pin 17, PC3 pin 18), both outside §3.10 and AN2606; about 38 left free |
| New quiescent current | **+238 µA** while running (0.17 % of the ~140 mA budget); **+0 µA in storage** |
| Board area | 5 × 0402/0603, about 4 mm², in the MCU analog corner (near pins 15–21) |
| Adopted from other lists | FMEA **H-1** (+3 parts / +1 part number) — a prerequisite for automated pyro-chain testing, irreplaceable; FMEA **H-3** (QSPI pull-ups, prerequisite for T-30) and **H-4** (VBUS pull-down, prerequisite for T-52) |
| Explicitly rejected | DESIGN_ASSURANCE's **R-ARMBYP** (it removes the arming plug's status as a "complete electrical break" — a whole independent protection layer — while H-1 provides the same cold-test capability for +3 parts **without touching the break**, and fails in the safe direction); 3V3 current sensing; the servo output readback network (5 parts); a BAT+ divider |

**If nothing is added**: D2 cold joints, L2 degradation vs buck undervoltage, pyro FET shorts and open pyro gate chains — all four classes pass the bench silently, and two of them are INJURY or VEHICLE_LOSS class. That is what these 5 parts (+ H-1's 3) buy.

### Summary

Today the board is almost blind to its own power chain: RAW is visible and 3V3A is visible for free through VREFINT, while BAT+, VLOGIC and 3V3 are invisible, so "D2 cold joint", "L2 cracked joint" and "buck output low" look like the same reading to firmware, or like no reading at all. Two dividers (5 × 0402/0603 in total, 0 new part numbers, two free ADC pins PC2/PC3, +238 µA running, +0 µA in storage) turn VLOGIC and 3V3 into numbers; together with three zero-part internal channels (VREFINT / VBAT4 / die temperature) and per-board divider calibration, the whole chain BAT+ → load switch → RAW → diode OR → buck → LC gets a reading at every stage boundary. The V_RAW − V_VLOGIC term in particular catches an open D2 — a single-point fault completely invisible on a bench where USB is always plugged in, which kills the board the moment it goes into the rocket. Automated pyro-chain testing adopts FMEA H-1 (BAT54A + 2 × 47k, +3 parts), turning "FET short" from something you can only discover by inserting the plug and watching it fire into a cold four-state reading with the plug out, plus a zero-part active-pulse test that covers the gate chain for the first time; DESIGN_ASSURANCE's R-ARMBYP is explicitly rejected because it removes the arming plug as a complete electrical break, a whole independent protection layer. The link ruling makes SWD primary (the RAM-resident self-test does not depend on the flight firmware existing or being correct, and GEOMETRY shows USB is unreachable once installed while J2 still has 1.88 mm) and USB CDC backup (the only thing that verifies USB itself, the only ppm-class SOF clock reference, and the log download path). The suite gives about 40 ordered checks with numeric criteria across three configurations CFG-A/B/C, including noise-floor criteria (σ = 0 means frozen data, closing the hole where WHO_AM_I still passes on a cracked joint), a QSPI quad-line proof, a watchdog proof, and a rail-transient test using the buzzer as a calibrated 95 mA load — which also replaces the rejected 3V3 current sensing and detects a mute buzzer without listening. Electrical readback of the servo channels (5 parts) and a BAT+ divider (positive injection into an unpowered pin) are ruled out, with the costs recorded. Output is a SWD-readable RAM result block + streamed lines + JSON (each check with stage/band/raw), written into the flight log header as record type 0x02.

## Change items

### [AT-1] netlist
- Parts: +3 | Part numbers: 0 | Complexity: low | Confidence: reasoned
- Add VLOGIC rail sensing: R-VL1 100k (C25741) from VLOGIC to a new net VLOGIC_SENSE; R-VL2 10k (C25744) from VLOGIC_SENSE to GND; C-VL 10 nF (C57112) from VLOGIC_SENSE to GND; VLOGIC_SENSE to U1 pin 17 (PC2, ADC12_INP12). Ratio 1/11: full battery 8.07 V → 733.6 mV, USB only 4.68 V → 425.5 mV, TVS clamp 19.55 V → 1777 mV (inside the TT 4.0 V limit).
- Prevents: D2 (SS34, RAW → VLOGIC) open or cold-soldered — the only path from the battery to the logic rail, completely invisible on a bench where USB is always plugged in, killing the board the moment USB is unplugged (i.e. put in the rocket); also catches a shorted D2 back-feeding USB 5 V onto the servo header and ARM terminal
- New failure: a shorted R-VL1 (100k) puts the full VLOGIC voltage (worst case the 19.55 V TVS clamp) directly onto PC2, above the TT class's 4.0 V hard limit, damaging the MCU analog front end; very low probability, but add VLOGIC_SENSE–GND = 10.0 kΩ and VLOGIC–VLOGIC_SENSE = 100 kΩ to the unpowered signature table. Also adds 73 µA of running current

### [AT-2] netlist
- Parts: +2 | Part numbers: 0 | Complexity: low | Confidence: reasoned
- Add 3V3 rail sensing: R-33A 10k (C25744) from 3V3 to a new net V3V3_SENSE; R-33B 10k (C25744) from V3V3_SENSE to GND; to U1 pin 18 (PC3, ADC12_INP13). Node 1.650 V nominal, 5.0 kΩ source, 165 µA. Deliberately no capacitor — T-16 must capture 3V3's sub-millisecond transient dip under a 95 mA step.
- Prevents: separates "buck output low" from "L2 / 3V3A stage degraded": the criterion is the ratio k = V3V3 / VDDA, normally 1.000, 1.83 with a 50 Ω crack in L2. Today, with VDDA = 1.8 V, the two faults read identically, and the H743 still runs at VDD = 1.8 V, both appearing as "MCU alive, all three sensors dead"
- New failure: 165 µA running current (0.17 % of budget). No capacitor means the channel is sensitive to switching noise on 3V3, so absolute criteria must use hardware oversampling (≥ 64×), or noise will cause false FAILs

### [AT-3] firmware
- Parts: 0 | Part numbers: 0 | Complexity: none | Confidence: verified
- Enable and log three zero-part internal ADC channels: VREFINT against VREFIN_CAL (0x1FF1E860) to solve VDDA (= 3V3A); VBAT/4 after ADC3_CCR.VBATEN to verify MCU pin 6's joint; VSENSE against TS_CAL1/2 for die temperature. Every ADC criterion is written as a ratio or a VREFINT-calibrated voltage; absolute millivolt windows are forbidden. Merged with FMEA F-12, not listed twice.
- Prevents: an open L2 (a 3 mm wirewound inductor in single string ahead of every sensor and the whole ADC scale) silently killing three sensors while four ADC channels read wrong together and consistently; and a cold joint on MCU pin 6 — today the only way to verify it is poking a probe onto a 0.5 mm-pitch leg
- New failure: if VDDA itself fails, the VREFINT reading fails with it, so it must first pass a plausibility gate (raw code not 0, not full scale, VDDA ∈ 2.0–3.8 V), reporting ANALOG_SUBSYSTEM_DEAD rather than a voltage when out of range. Otherwise it outputs a plausible-looking false number

### [AT-3b] procedure
- Parts: 0 | Part numbers: 0 | Complexity: low | Confidence: reasoned
- Per-board divider calibration: after assembly apply a known 8.000 V to the BAT terminal from a bench supply and record the PC4/PC2 ADC codes; record the PC3 divider ratio using the VREFINT-calibrated VDDA. Write the three coefficients into the configuration block, covered by its CRC32. Once per board, about 5 minutes, zero parts. An uncalibrated board may still run, but the related checks are downgraded to DEGRADED(uncalibrated) in the report.
- Prevents: 1 % resistors give ±1.4 % divider-ratio uncertainty while D2's forward drop is only 0.35 V — uncalibrated, AT-1 can only catch a fully open D2, not "a degrading cold joint" (a few ohms of contact resistance). Calibrated, the window tightens from ±0.16 V to ±0.03 V
- New failure: the calibration itself might be taken on a board that is already faulty (e.g. L2 already degrading), freezing the fault in as "normal". Mitigation: calibrate only after the whole unpowered DC signature table has passed, and apply a plausibility window to the calibration values themselves (reject writing a divider ratio more than 3 % off nominal)

### [AT-4 (= FMEA H-1)] component
- Parts: +3 | Part numbers: +1 | Complexity: medium | Confidence: reasoned
- Adopt FMEA H-1 as is: 3V3 → BAT54A common anode; cathode 1 → 47k (C25792) → PYRO1_OUT; cathode 2 → 47k → PYRO2_OUT. +2 × 47k 0603 + 1 × BAT54A SOT-23. Belongs to H-1; do not double-count against the FMEA list when merging.
- Prevents: pyro FET drain-source short (FMEA I-1) — today, with the ARM plug out, healthy FET / shorted FET / open igniter / no igniter all read 0 V, and the only "test" is inserting the plug and seeing it fire; with the plug in, a shorted FET has already fired the charge. H-1 turns it into a cold four-state measurement before the plug goes in
- New failure: a shorted 47k pull-up is an INJURY-class path (with ARM inserted the drain is clamped to 3.3 V, 5.1 V across the bridgewire → 5.1 A, immediate fire); the BAT54A is there to block exactly that; a shorted BAT54A plus a shorted resistor is a double fault. An open BAT54A = cold test reads all zeros = false "FET short" = scrub, the safe direction. The three ADC nodes become one simultaneous resistor network and must be read jointly, not channel by channel

### [AT-5] firmware
- Parts: 0 | Part numbers: 0 | Complexity: low | Confidence: reasoned
- Pyro gate pull-down integrity self-test (zero parts): temporarily configure the PYRO1/2_GATE pins as inputs with the internal pull-up enabled (30/40/50 kΩ on the H7) and read the level. The external 1k pull-down holds the node at 3.3 × 1/41 = 80 mV, so it must read 0. Reading 1 means R17/R21 missing or open: the board refuses to arm and sounds a dedicated tone code. Must run with the ARM plug out.
- Prevents: R17/R21 (the pyro gate 1k pull-downs) tombstoned or cold-soldered — the only thing holding the pyro gates down at power-up, while 0402 tombstoning is JLC's most common assembly defect and the node has no means of observation today short of a meter
- New failure: during the test the gate is lifted to 80 mV (8.1× margin against the AO3400A's corrected Vgs(th) min of 0.65 V, safe); but this code is the only place allowed to configure a pyro gate as an input, so it must live in the same file as pyro_may_fire() under the same CI grep, or it becomes a second writer bypassing the single choke point

### [AT-6] firmware
- Parts: 0 | Part numbers: 0 | Complexity: medium | Confidence: reasoned
- Pyro active-conduction self-test (zero parts, needs H-1): with the ARM plug out and no igniters, drive each gate high for 10 ms in turn; that channel's PYRO*_CONT must collapse to < 8 mV and recover within 2 ms. The request must go through a PYRO_TEST request type of pyro_may_fire(), with preconditions ARM_SENSE < 20 mV and VBUS present and state == SELFTEST, and the pulse width capped at 10 ms in hardware by a TIM2 output compare.
- Prevents: the whole gate chain (470R series, gate bond, FET body, MCU pin configuration) is 100 % uncovered today — with an open anywhere, PYRO*_CONT still reads a normal 0.764 V and the self-test certifies a dead channel as healthy (DESIGN_ASSURANCE Tier 2 item 8)
- New failure: it is the only code path in the project that drives a pyro gate high outside flight. If the preconditions are wrong or the SELFTEST state can be entered by mistake, it is a self-fire path. It must share the same function and CI constraints as pyro_may_fire(), and the TIM2 hardware timeout must be loaded on the same gate rising edge. Bridgewire current is about 70 µA (from the other channel's pull-up), not zero

### [AT-7] firmware
- Parts: 0 | Part numbers: 0 | Complexity: medium | Confidence: reasoned
- A standalone RAM-resident self-test program (< 8 KB, linked at AXI SRAM 0x24000000), loaded and run over SWD by pyOCD/OpenOCD, depending only on the core + RAM + clocks + ADC, not on whether the flight firmware exists, is correct or has hung. Results go into a struct at a fixed address (magic 'RKTP' + version + monotonic sequence + an array of check records), read directly from memory by the agent.
- Prevents: the scenario "an agent plugs into a freshly soldered board with no firmware yet" is not possible today; nor is self-testing once the firmware has hung — exactly when a self-test is needed most
- New failure: the self-test and the flight firmware are two code bases whose criteria may drift apart (the self-test says PASS while the flight code refuses to arm on a different threshold). Mitigation: both must share one criteria header, the criteria table is the single source of truth, and CI checks consistency between the two

### [AT-8] procedure
- Parts: 0 | Part numbers: 0 | Complexity: none | Confidence: verified
- Link ruling: SWD (J2) primary, USB CDC backup. J2 must be fitted, never DNP (consistent with DESIGN_ASSURANCE §4.6; one more reason here: it is the main test port). SWD cables must be fly leads or low-profile right-angle housings, not standard shielded ribbon housings — GEOMETRY_REV_G gives only 1.88 mm of crimp-housing margin at J2. Explicitly no USB pigtail.
- Prevents: USB CDC only works once a lot already works (oscillation, HSE, PLL, PHY, connector, firmware enumeration); making it primary means it carries the least information exactly when diagnosis is most needed; and GEOMETRY_REV_G §3.4 has already ruled that the USB plug shell cannot reach the board once installed (only 3.80 mm radial at the edge)
- New failure: needs a $10–20 probe, and DESIGN_ASSURANCE's J2 reorder makes it physically impossible for a 2.54 mm jumper to select DFU — entering DFU needs a fly wire or tweezers. SWD cannot diagnose the USB peripheral, the USB-C connector or D+/D− routing at all; those are covered only by T-22/T-60

### [AT-9] test
- Parts: 0 | Part numbers: 0 | Complexity: medium | Confidence: reasoned
- About 40 ordered automatic checks with numeric criteria, in three levels: CFG-A (bare board + USB, about 90 s, fully automatic) / CFG-B (+ battery + switch, about 30 s) / CFG-C (full vehicle, about 3 min including explicit manual steps). Each carries a prereq and is marked SKIPPED(prereq) if unmet, so the first FAIL is the localised stage. Full table in §5.
- Prevents: unactionable conclusions like "something is wrong somewhere". Today no board-level acceptance test with numeric criteria exists at all (MARGIN_PRESCRIPTION P1-14 only says one must)
- New failure: windows written too wide miss faults; too narrow and part tolerance and temperature produce false FAILs, and a test that rejects good boards is worse than none (DESIGN_ASSURANCE gave the same lesson on incoming screening). Mitigation: measured values from the first 5 boards are written back into the criteria table, and AT-3b's per-board calibration shrinks the windows from component tolerance to device tolerance

### [AT-10] document
- Parts: 0 | Part numbers: 0 | Complexity: low | Confidence: reasoned
- Machine-readable output specification: ① a SWD-readable RAM result block (magic + sequence, localising even a hang to one specific check); ② streamed line output (RTT or CDC), sent as it runs, not buffered; ③ a final JSON with id/name/stage/prereq/value/unit/band/verdict/raw/localises per check and verdict/first_fail/failed_stage at the top level; ④ the same JSON written into the flight log header as record type 0x02, right after the already-defined 0x01 header.
- Prevents: an agent parsing prose; the most informative failure — "the self-test hung and never returned" — being unlocatable (batched output swallows it whole); and being unable to tell afterwards, from a board that came back in pieces, how the board saw itself before launch
- New failure: once fixed, the stage enumeration is what agents act on, and renaming it silently breaks their handling logic — the enumeration must be versioned (the schema field) and only ever extended, never changed

### [AT-11] firmware
- Parts: 0 | Part numbers: 0 | Complexity: low | Confidence: reasoned
- Rail load-step test (zero parts): the buzzer as a calibrated 95 mA load. ① first a 200 µs pulse, aborting immediately if Δ3V3 ≥ 0.30 V; ② then 5 ms DC, capturing the transient on PC3 at about 1 MSPS: dip 15–120 mV, recovery < 200 µs, VDDA never below 3.10 V. A dip < 3 mV means the buzzer branch is open; > 250 mV or no recovery means D6 reversed / shorted coil / missing buck output capacitors or saturating inductor.
- Prevents: a mute buzzer (the only working status channel inside a closed airframe) can today only be judged by ear; a reversed D6 pulls the 3V3 rail down once per 2.7 kHz cycle the first time the buzzer sounds; and the buck's load-transient response is not measured at all today
- New failure: this code deliberately digs a 95 mA hole in the 3V3 rail during self-test; if the 200 µs pre-check's abort logic is wrong, a board with a reversed D6 is shorted for 5 ms. The pre-check must act first at the hardware level, and the abort path must not depend on any interrupt

### [AT-12] firmware
- Parts: 0 | Part numbers: 0 | Complexity: low | Confidence: verified
- QSPI quad-line proof (adopting DESIGN_ASSURANCE §4.4): read JEDEC ID = EF 40 18 → set QE → write a 256-byte LFSR pattern to a reserved scratch page in 1-4-4 → read back in 4-4-4 and compare byte by byte, 0 byte errors. ID passing while quad fails localises to PE2 (IO2) or PD13 (IO3) open.
- Prevents: a 0x9F ID read runs in 1-1-1 mode using only IO0/IO1 and still returns a perfect EF 40 18 with PE2 and PD13 completely disconnected — and the design deliberately removed the WP/HOLD pull-ups, so those lines float when open. The flight log would fail only in flight
- New failure: writing one page every boot consumes the scratch page's endurance (W25Q128 about 100k cycles; 10 boots a day lasts 27 years — acceptable, but the scratch sector must be physically separate from the log area, and a write failure must not block boot)

### [AT-13] firmware
- Parts: 0 | Part numbers: 0 | Complexity: low | Confidence: reasoned
- Sensor noise-floor criteria (zero parts): IMU 2048 samples at rest, \|a\| = 1.000 ± 0.05 g, per-axis gyro σ ∈ [0.010, 0.30] °/s, per-axis accel σ ∈ [0.5, 8.0] mg, ≤ 2 identical consecutive samples; MS5611 100 samples at rest at OSR4096, σ ∈ (0.002, 0.020] mbar; three-temperature cross-check \|T_die − T_baro\| ≤ 15 °C, \|T_imu − T_baro\| ≤ 5 °C.
- Prevents: WHO_AM_I still passes on a cracked joint, a cracked die or a stuck DMA — σ = 0 is the only signature of a frozen data path; the σ upper limit also discriminates a relabelled MS5607 (datasheet RMS resolution 0.024 vs 0.012 mbar) and degrading joints
- New failure: σ criteria are sensitive to the environment — a vibrating bench or people walking around produces false FAILs. The criteria must define "at rest", and on failure retest once before judging, so false rejections don't make people abandon the whole discipline

### [AT-14] test
- Parts: 0 | Part numbers: 0 | Complexity: low | Confidence: verified
- Watchdog proof test: in CFG-C deliberately stop feeding; the IWDG must reset within 380–480 ms, and RCC_RSR.IWDG1RSTF must be 1 afterwards.
- Prevents: a watchdog that was never enabled, or silently disabled by some refactor — the difference between "a watchdog" and "a comment", and FMEA ruled the IWDG chain the most important ruling on this board
- New failure: this test really resets the board, so it must be the last item of every self-test sequence and must not run with the ARM plug inserted (after the reset, rule 4 powers up DISARMED — the safe direction — but it would interrupt other tests in progress)

### [AT-15] test
- Parts: 0 | Part numbers: 0 | Complexity: low | Confidence: reasoned
- Vent test (zero parts): close the bay and warm it gently for 5 minutes, logging the MS5611's P and T together; criterion \|dP/dT\| < 0.5 mbar/K. An unvented sealed bay gives, by the ideal gas law, P/T = 1013/293 = 3.46 mbar/K, a 7× separation.
- Prevents: the static port has no specification at all (DESIGN_ASSURANCE Tier 3 item 11: an unvented bay = the barometer reads bay pressure; sealed at 20 °C and sun-heated to 60 °C it reads about 14 % high by the ideal gas law), while the barometer is the mandatory primary apogee source
- New failure: the test turns a mechanical/assembly property into an electrical criterion and may lead people to think "tested once, vented forever" — vents get blocked by residue, tape or coating, so it must be a routine item after every airframe closure, not a one-time acceptance item

### [AT-16] firmware
- Parts: 0 | Part numbers: 0 | Complexity: low | Confidence: reasoned
- Three clock criteria (zero parts): ① RCC registers HSERDY = 1 / PLL1RDY = 1 / SWS = PLL1 / CSS not triggered (proves the HSE oscillates); ② mean of 8192 IMU DRDY intervals 1250 µs ± 3 %, jitter σ < 5 µs (cross-checks against the IMU's own oscillator, also discriminating a relabelled 42688 with no 800 Hz step); ③ with USB enumerated, SOF interval 1000.0 µs ± 0.05 % (the board's only ppm-class reference, derived from the host crystal).
- Prevents: the HSE oscillating at the wrong frequency (wrong crystal or wrong CL) — RCC registers prove oscillation, not frequency; a wrong 25 MHz breaks USB enumeration, log timestamps and every integrated quantity at once
- New failure: criterion ② depends on the IMU's internal oscillator accuracy (a few percent), so a 3 % window only catches gross errors; criterion ③ is only available with USB present. With both unavailable only the RCC bits remain, which the report must mark DEGRADED, not PASS

### [AT-17] netlist
- Parts: 0 | Part numbers: 0 | Complexity: none | Confidence: reasoned
- Reject DESIGN_ASSURANCE's R-ARMBYP (RAW to PYRO_BUS through two 47k in series). Not implemented.
- Prevents: keeps the arming plug's status as a complete electrical break — a whole independent protection layer (layers, not margin, are what requirement 2 asks for). The zero-energy pyro-chain test capability R-ARMBYP offers is provided by FMEA H-1 for +3 parts without touching the break at all, and H-1 fails in the safe direction (BAT54A open → cold test reads all zeros → false "FET short" → scrub)
- New failure: none. But two entries in DESIGN_ASSURANCE §4.2's unpowered signature table were written assuming R-ARMBYP is fitted (J4.4–GND ≈ 10.5 kΩ, ARM_SENSE–GND becoming safety-critical); after the rejection they must revert to 11.0 kΩ and non-safety-critical, or the next reader will stop work over the wrong table

### [AT-18] component
- Parts: 0 | Part numbers: 0 | Complexity: none | Confidence: reasoned
- Reject 3V3 rail current sensing (shunt + current-sense amplifier). Not added. Replaced by two zero-part substitutes: AT-11's load-step transient test, and numeric criteria in the procedure for the bench supply's own ammeter (at 200 MHz / VOS3 idle with all sensors on and GPS locked, the 3V3 branch draws 128–184 mA; the whole board 75–120 mA at 8.4 V; outside that, stop).
- Prevents: putting two new solder joints in series with the MCU's only supply path — the same reason the frozen document deleted the 0 Ω sense jumper and DESIGN_ASSURANCE refused to add it back. The only extra fault current sensing catches (a partially shorted decoupling capacitor with the rail still in spec) costs heat and endurance, not the mission
- New failure: accepted blind spot: a partially shorted 3V3 decoupling capacitor (say 50 Ω) draws an extra 66 mA without moving the rail, invisible to firmware. It shortens endurance and warms the buck but changes no mission criterion. Caught once at assembly by the bench-supply current criterion

### [AT-19] component
- Parts: 0 | Part numbers: 0 | Complexity: none | Confidence: reasoned
- Reject the servo output readback network (4 × 100k from each SERVO*_OUT summed to one node + 1 × 100k to ground → one free ADC pin, 5 parts total). Not added.
- Prevents: bringing an off-board signal (the servo signal line) into a new ADC pin through 100k — when a J5 numbering error or harness chafe puts 8.4 V on a servo signal line, that path forward-injects about 50 µA into the pin, exactly the class of path this design keeps closing; and the candidate ADC pins PA4/PA5 have IINJ of 0/0 mA. Also, the servo channels already need one unavoidable manual step (sweep the fins to confirm the sign, the number-one killer), so automating the electrical half buys little
- New failure: accepted blind spot: an open 220R or a dead SRV05-4 channel is invisible to firmware. Covered by the unpowered signature table (each J5A pad reads 10.22 kΩ to ground = R24 + R28; nothing else on the connector reads that value) and the mandatory manual sweep. T-50 does register-level checks only and the report says honestly "no board-side electrical coverage"

### [AT-20] component
- Parts: 0 | Part numbers: 0 | Complexity: none | Confidence: reasoned
- Reject a BAT+ (upstream of the load switch) divider. Not added. Replaced by T-15's two-state reading: on USB power with the MCU alive, RAW ≤ 0.15 V with the switch open and 6.00–8.45 V with it closed.
- Prevents: a permanently live divider path — with the board off VDD = 0 while the node sits at 2.7 V, forward-injecting about 77 µA through the ADC pin's ESD structure into the unpowered VDD rail and holding the MCU in an undefined half-powered state; exactly the class the frozen document closed when it stopped taking the pyro bus from raw BAT, and a violation of the FT pins' own "no positive injection at all" rule. It also saves 57 µA of battery drain in storage
- New failure: accepted blind spot: with the switch open the battery is invisible to firmware, so when T-15 fails {flat battery / reed switch / J1 SW cold joint / Q1-Q2} remain indistinguishable. Closed by an instrument-free action — swap in a known-good battery pack and test again; failing twice localises to the board (switch terminal or load switch)

### [AT-21] firmware
- Parts: 0 | Part numbers: 0 | Complexity: none | Confidence: reasoned
- A mandatory note, checked in CI: LQFP100 pins 17/18 are the merged PC2_C/PC3_C pads, and SYSCFG_PMCR's PC2SO/PC3SO reset to 0 (analog switch closed = the pin is ordinary PC2/PC3 + ADC12_INP12/INP13). No initialisation code may set these two bits. ADC1 scans the six external channels (PC0/PC1/PC2/PC3/PC4/PC5), ADC3 the three internal ones.
- Prevents: copying an H7 template that sets PC2SO/PC3SO to 1 and silently disabling both new rail senses — the failure looks like a plausible number, not a missing reading
- New failure: no new hardware failure. It introduces a firmware convention that must be followed; the mitigation is reading back SYSCFG_PMCR at self-test start and writing its raw value into the report's raw field

### [AT-22] firmware
- Parts: 0 | Part numbers: 0 | Complexity: low | Confidence: unverified
- Battery / harness resistance trend criterion (zero parts): step all four servos together, record the RAW dip on PC4, compare with the baseline recorded at build, and warn on a change > 30 %. The absolute value is unavailable (no current sensing); the trend is.
- Prevents: battery ageing, loose screw terminals and degrading harness crimps — all three invisible in static voltage, while deployment shock pulls directly on the DB128V screw clamps (DESIGN_ASSURANCE lists the connector/harness interface as the board's number-two environmental enemy)
- New failure: the baseline was taken with one particular battery and is void after a pack change — the criterion must be stored per (board UID, battery pack ID) pair, or it produces floods of false warnings and people learn to ignore it. The servo step really moves the fins, so it must only run after confirming the fins are unobstructed

### [AT-23] test
- Parts: 0 | Part numbers: 0 | Complexity: low | Confidence: verified
- Pull-pin test and firmware latch (adopting DESIGN_ASSURANCE's ruling; no pin change): maintain pin_was_seen_installed, set only after PD14 has read low continuously for 500 ms; the READY gate requires the latch true and PD14 currently high. Automated part: after the agent prompts "pull the pin", poll; the criterion is a clean 0 → 1 transition within 50 ms with < 3 bounces.
- Prevents: the pull-pin interlock fails toward armed — open = 3.30 V = "pulled, permitted", so cold joints, broken wires and corrosion all read as permitted, and the final flight-enable interlock silently does not exist
- New failure: residual: a wire that breaks after boot but before the pin is pulled is still indistinguishable from a pull (a property of any pull-pin interlock). The operating cost is that the pin must be physically inserted before every power-up, or the board never reaches READY — exactly the discipline wanted. Must be paired with FMEA H-10 (BAT54S clamp), otherwise a pull-pin wire chafing onto 8.4 V lifts PD14 to 7.94 V, above the 7.3 V absolute limit

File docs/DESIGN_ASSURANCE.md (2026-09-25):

# Rocket Flight Computer v1 — Design Assurance Plan

> Inputs: `ROCKET_FC_FROZEN_DESIGN.md`, the as-drawn netlist (78 nets / 370 connections / 104 references, machine-checked this round) and the schematic notes.
> Status at the time of writing: schematic captured, **PCB not yet laid out**. Every "before fab" action in this plan was still free at that point.

---

## 1. Direct answers to the three questions

**(1) Manufacturing errors.** You are not a factory: no inspection line, 5 boards, through-hole parts soldered by hand. So the strategy is not "add inspection" but **delete the error's degrees of freedom from the design, and catch the rest with an unpowered DC signature table**. This board is unusually rich in unpowered evidence: every safety-critical node has a unique resistor or diode signature readable with a $20 multimeter on an unpowered board — each of J5's four signal pins reads 10.22 kΩ to ground (`R24 + R28`) and no other pin reads that value; each pyro FET drain reads 11.0 kΩ (`R18 + R19`), a shorted part < 1 kΩ; each pyro gate reads 1.00 kΩ (`R17` / `R21`) — the only thing holding PE4/PE5 down at power-up; `GND → BAT+` in diode mode reads OL both ways, proving the bidirectional SMBJ12CA was fitted rather than a unidirectional SMBJ12A that would short a 25C LiPo. **Add one rule: every board's first power-up is always USB first, then a current-limited bench supply, never a battery first.** On USB, `RAW ≈ 0 V` (D2 reverse-biased) and there is no 8.4 V on the servo header at all — this rule downgrades a wrong J5 numbering, a reversed polymer can, a `BAT+/BAT−` bridge and a reversed SOT-23-6 array from "fire" to "supply goes into constant current". The only place worth spending money: **buy JLC's through-hole soldering** (about $4 per order, *unverified whether the Economic tier offers it*), which removes the project's two most dangerous assembly defects (a cold joint on J1's SW pins, bridges on J1/J4) by prevention rather than detection. If it cannot be bought, give every plane-connected through-hole pad thermal relief, otherwise a hand iron cannot heat through a GND pin tied to inner planes on a 4-layer 1.6 mm board.

**(2) Environment.** Quantify the environment first, then **refuse half of what is usually done**. Amateur high-power flight has only 0.5–4 s of boost vibration — 200–800 stress cycles at a 200 Hz first mode, about 12,000 cycles over 20 flights. Steinberg's 0.355 mm allowable displacement is a **2 × 10⁷-cycle** criterion; scaled to 600 cycles with his own fatigue exponent b = 6.4 it is about 1.8 mm, against an actual 3σ displacement of 0.352 mm → **about 5× margin**. So: **no mid-span support, no potting the board to its bracket, no RTV on the two 470 µF cans**. The board's real environmental enemies, in order: landing and deployment shock (single overloads: 92 g @ 20 mm crush / 367 g @ 5 mm on hard ground / 1593 g ballistic; GEVS Fig 2.4-1's benign box is 500 g), **the connector/harness interface** (deployment shock pulls directly on the DB128V screw clamps), and **a hot bay nobody has measured** (MIL-STD-810H Method 501.7 §2.3.2 enclosed-compartment intensified solar: 71–85 °C). The three corresponding actions are all cheap: ferrules + torque-stripe paint, a zip-tie hole on each side of J5 to hold down the four plug housings, and writing the MS5611 temperature word into every 1 Hz record. **Conformal coating: not done** — reasons in §6. *(MARGIN_PRESCRIPTION.md later overturned two of these: staking of the 470 µF cans and conformal coating are now mandatory.)*

**(3) Errors in the design itself — this is the centre of gravity, and redundancy is structurally useless here.** All four servos get the same wrong sign; all five boards use the same wrong footprint pad mapping; both pyro channels run through the same wrong apogee code. Redundancy copies **the same error**. Only three things actually work, in order of effectiveness:

- **Before spending money, run a deterministic procedure that checks what ERC/DRC structurally cannot see.** ERC/DRC work only on the netlist graph; they do not know what a footprint looks like or what a datasheet says. The three items in the schematic notes (J5 rows/columns, LS1's second terminal, MS5611 SDO) all got in **because someone happened to notice**, not because a process caught them. Make it a process: export pad coordinates for the 11 parts whose "symbol pin number cannot be inferred visually from the footprint", and check them against the manufacturer's pin table (**not against the schematic symbol — the symbol is the thing under test**). 30 minutes. Using the same method this round found three new defects in an hour (below).
- **Let wrong assumptions be falsified by physics, not confirmed by your own tests.** A test corpus you synthesised yourself carries the same wrong mental model you had while writing the code — it just moves the common-mode error up one level. The only thing that can falsify it is **real data**: a first flight as a pure data logger, arming plug removed, no igniters, servos unplugged, a commercial altimeter with sole deployment authority. Transonic pressure anomalies, gyro bias temperature drift, the closed-bay thermal curve and the real vibration spectrum only have ground truth in flight.
- **Make what cannot be made redundant structurally impossible to get wrong.** A single choke-point function `pyro_may_fire()` (CI greps and forbids any other write to PE4/PE5), a hardware timeout on the 20 ms fire pulse (fully decoupled from the IMU), apogee detection and the state machine as pure functions that compile on a host.

---

## 2. Where it is most likely to go wrong (sorted by probability × consequence)

### The project's observed defect rate — the basis for extrapolation

This round found or confirmed the following, all reproducible:

| # | Defect | Evidence |
|---|---|---|
| a | **C27 missing** — BOM §4.2's fifteen 100 nF include "pull-pin RC", but the netlist has `PULLPIN = {R36.1, R37.1, U1.61}` with no capacitor | 104 references in the netlist; the C sequence C1..C36 is missing only C27; 35 capacitors actual vs 36 in the BOM; 100 fitted vs 101 in the document. R6 is only a skipped number (38 resistors, count matches), not a missing part |
| b | **Frozen §5.4 omits ICM-45686 pin 6 = GND** (power ground) | The document lists only 2, 3, 7, 10, 11 as grounded, naming 13 of 14 pins; the netlist connects U4.6. **The schematic is right; the document is wrong.** The document's preamble says "anything not written here does not exist" — an agent drawing strictly to the document would leave the LGA-14's power ground floating, on a package that cannot be reworked |
| c | AO3400A `Vgs(th)` written as 0.4–1.1 V; datasheet Rev 3.1 says **0.65 / 1.05 / 1.45 V** | Affects the §1 pyro pull-down argument and §3.9. Corrected, the 1k pull-down's 0.065–0.106 V is a **6.1× margin** against 0.65 V (not 3.8×) — a stronger conclusion, but the numbers must change |
| d | The 75 pF in the Miller argument is **Coss, not Crss**; Crss = 50 pF | Combined with (c), Miller margin is **6.8×** (95 mV vs 0.65 V); the oscilloscope acceptance gate is no longer needed |
| e | SAM-M10Q velocity limit written as 20,000 m/s; datasheet UBX-22013293 R05 says **500 m/s** | Off by 40×. The real consequence is a degraded/lost fix for the fastest few seconds of boost and reacquisition in coast (the COCOM hard cut-off needs > 18 km and > 515 m/s together), not a hard cut-off |
| f | The "1.487 V free no-battery detection" is **miscalculated** | It equals VBUS minus one SS34 drop, i.e. it assumes D2 is forward-biased; but D2's anode is on RAW and its cathode on VLOGIC, so on USB power it is **reverse-biased**, and RAW is set only by leakage (SS34 reverse leakage vs the 470 µF self-leakage), in practice near 0 V |
| g | The MS5611's full-accuracy range is **450–1100 mbar** (≈ 6.3 km); 10–1200 mbar is the "ADC linear range" | The document's "usable all the way to 10 mbar ≈ 31 km" was one of the arguments for deleting the ADXL375, and it does not hold |
| h | `J1.3` and `J1.4` are both on net `SW_TERM`; **there is no switch return pin** | Document §5.1 says the external switch goes across `SW_TERM` and GND; the "SW SW" silkscreen invites wiring the switch across 3–4 (open circuit, board never powers up), or stuffing the return wire into `J1.2`'s BAT− clamp together with the 16 AWG battery negative |
| i | Each of J7's nine LoRa signal nets **has only one connection** (J7 only) | "LoRa deletion is reversible" does not hold. And `J7.1 = 3V3` and `J7.2 = GND` are adjacent bare holes — one wire whisker shorts the 3.3 V rail |
| j | Reference conflicts: the document has J1 = USB-C / U2 = W25Q128, the schematic has J1 = battery terminal / U2 = AP63203 / U3 = W25Q128 | Two "sources of truth" disagree on references |
| k | Board width contradicted in three places: frozen document 50 mm, the brief 40 mm, `PCB_PIPELINE.md` 40 mm | The document's own §1 says "no terminal arrangement fits a 40 mm edge" — if 40 mm is the current truth, **the terminal layout and the design do not work** |
| l | `PCB_PIPELINE.md` uses net names that do not exist (`PYRO1_FIRE` / `PYRO1_RTN` / `VBAT_SERVO` / `VSERVO` / `SERVO_GND`), a 40 mm board width and a 7.5 A servo bus, and admits "the dossier does not contain this board's real netlist" | **The most dangerous document at the time, because it would drive routing** |
| m | The `_N` suffix (`PYRO1_GATE_N` / `PYRO2_GATE_N` / `BUZZ_GATE_N`) suggests active-low, but they are all active-high | The net names actively persuade a firmware author to do what §7 rule 2 forbids (drive high at power-up) |
| n | Three system-level gaps: **no transonic lockout, no on-pad gyro bias re-calibration, no static-port specification** | Zero hits in a full-text search |

> One correction to an item **the brief listed as a known error, which does not hold on re-check**: the IPC-2221 internal formula `I = 0.024 · ΔT^0.44 · A^0.725` with 1 oz × 40 mm = 2170 mil² at ΔT = 10 °C gives **17.3 A** — the frozen document's number is right, and the rebuttal "really only ~9.5 A" cannot be reproduced. Recorded honestly because it changes the base rate. *(MARGIN_PRESCRIPTION.md later pointed out that the number, while arithmetically right, is a 3× extrapolation of the IPC chart and should not be quoted.)*

**Extrapolation:** five independent review rounds, each still finding new defects, with no plateau in the rate. 370 connections, 104 footprints, 39 part numbers, 468 lines of specification, 9 self-admitted unverified items — an honest estimate is **5–15 still undiscovered, 1–3 of them fatal-class**. That number directly determines the answer in §8.

### Ranking

**Tier 1 — redundancy completely useless; consequence is the vehicle + people**

1. **Control-loop signs: gyro Z-axis sign × servo direction × board mounting orientation.** Zero words about it in three documents. This is an actively roll-controlled rocket whose controller integrates gyro rate; if any sign is reversed it is positive feedback, and all four fins go hard-over within a fraction of a second after lift-off. Completely silent on the bench (feedback is zero while the board is still). All four servos get the same wrong sign — a textbook common-mode design error. **Probability no lower than 1 in 4; consequence the vehicle plus an unpredictable landing point.**
2. **Transonic pressure anomaly triggering deployment.** §7 rule 7 makes the barometer the primary apogee source and says nothing about Mach. At Mach 0.8–1.2 the pressure at the static port is not free-stream pressure; the classic result is a huge false altitude jump, which a naive dP/dt sign-flip test reads as apogee — deploying at maximum dynamic pressure. **The hobby's most famous environment-induced failure**, and redundancy is useless: every redundant barometer sees the same false pressure.
3. **Row/column numbering of the J5 3×4 header (known, unresolved).** If the footprint is row-major: physical columns 1 and 4 happen to be right, column 2 = (RAW, GND, SIG4), column 3 = (GND, SIG3, RAW). **The consequence was underestimated last round**: with a servo plugged in normally, 8.4 V lands on its signal pin while its own V+ is at board ground — current flows through the servo's internal signal-input ESD clamp diode to ground, a path that **does not pass through the 220R** (the 220R is in the servo signal branch; the fault current does not use it), and RAW has **no fuse at all** (the 5 A fuse is in the arming plug and protects only the pyro branch). An unfused 25C 2S LiPo → 2.54 mm header → a servo ESD diode, in a closed electronics bay. **That is fire-class, not "the servo broke".** And it **half works** — a bench test with one servo plugged into column 1 passes.
4. **Symbol ↔ footprint pad-number mapping errors (J5 is only one instance).** Same class: LS1 (4 pads, only pin 1 named; which two are the electrical terminals is unchecked), LED1/LED2 (opposite anode numbering), D6 (is SOD-323 pin 1 the cathode?), Q1/Q2 (is the DFN5×6-8 exposed pad numbered 9 and is it the drain — the netlist uses `.9`, and that pad carries 12 A), U4/U5/U6, J1/J4 (which physical screw position is pad 1), Y1, J3 (USB-C A/B pad naming). **ERC and DRC are structurally blind to this class**, because both work on symbol pin numbers, and the symbol ↔ footprint mapping is exactly what neither checks. Identically wrong on all five boards.

**Tier 2 — single point, silent, only shows up in flight**

5. **Cold joints/bridges on hand-soldered through-hole parts.** The most dangerous is `J1`'s SW pin: `SW_TERM` carries only 76 µA (`R2` = 10k), so a marginal joint conducts perfectly on the bench with no self-heating and no voltage drop to reveal it; vibration and 20–30 g axial load pull it open → the back-to-back load switch turns off → the whole board loses power with only 18.2 ms of hold-up on `VLOGIC`. Next most dangerous: a bridge between `J1` BAT+/BAT− (hidden under the terminal body) and bridges between adjacent `J4` positions.
6. **The IWDG's single feed point (IMU DRDY ISR) + §7 rule 4 (never auto-re-arm after reset) = any watchdog reset in the air guarantees no deployment.** Each rule is right on its own; coupled they are fatal: any 2 s ISR stall in flight → MCU reset → powers up DISARMED per rule 4 → a healthy, living flight computer, deliberately forbidden by itself, rides a ballistic recovery. And with no backup record, afterwards you cannot tell "the charge didn't go" from "the computer refused to fire".
7. **The 20 ms fire pulse is only accounted for in an ISR; there is no hardware timeout.** Fire decisions run in the DRDY ISR (rule 1). If the IMU stops exactly during a pulse, the gate stays high until the watchdog reset ~2 s later — 2 s × about 5 A through a SOT-23. The device is destroyed, and it is an ignition source.
8. **`PYRO*_CONT` gives zero coverage of the switching element.** The divider only looks at the drain. Any open in the gate chain (cold joint on Q3 pin 1, cold joint on `R16`/`R17`, a FET that went open after a previous overcurrent, a firmware pin misconfiguration, a footprint G/S swap) still reads a normal 0.764 V. **The on-board self-test certifies a dead channel as healthy** — the worst class of defect.
9. **An igniter wired into an ARM position (counting from the wrong end).** The 6-pos terminal is ARM/ARM/E1/E1/E2/E2: six identical screw positions distinguished only by silkscreen, and nearly a palindrome. The real mechanism is **not an off-by-one** (every off-by-one on J4 was walked through and all are benign: pins 2/3/5 are on the same net, and landing on PYRO_BUS is harmless) but **counting from the wrong end**: mapping E2's 5→6 onto physical 2→1 = PYRO_BUS→RAW, so the igniter becomes the arming link itself, sitting on always-live RAW, while the arming plug sits across PYRO2_OUT and PYRO_BUS. The channel still fires normally, so it is never exposed; the 5 A fuse is in the wrong branch. `ARM_SENSE` and both `CONT` lines read a normal 0.764 V. **Updated consequence**: at fire time the igniter in the ARM position and the one on E1 go off together; the burnt bridgewire then permanently cuts PYRO_BUS's only supply → **the main never fires**.
10. **No on-pad gyro bias re-calibration + closed-bay self-heating.** Bias is taken on a cool board at power-up; the board then self-heats 10–20 °C while waiting on the pad (the review's own 5–15 °C self-heating estimate + sun), the ICM-45686 bias drifts ~0.5–1 °/s, and the controller faithfully commands a steady roll to cancel a rotation that does not exist. Silent, not on any checklist, and every board drifts the same way.

**Tier 3 — high probability but bounded consequence, or high consequence but low probability**

11. A string of MS5611 items (all from the datasheet, none considered in the design): **only 66 % of the offset recovers within 7 days after reflow** (absolute accuracy in the first week cannot be trusted and must not be stored as calibration); **full error band −20..85 °C is ±3.5 mbar = ±29 m** (a 10–20 % error on a 150–300 m main-deployment altitude); **450 mbar full-accuracy lower limit**; **no cleaning**; **no static-port specification at all** (an unvented bay means the barometer reads bay pressure; sealed at 20 °C and sun-heated to 60 °C, ideal-gas behaviour reads about 14 % high).
12. **The pull-pin fails in the wrong direction**: open = 3.30 V = "pin pulled, enabled". Cold joints, broken wires and corrosion all read as enabled. The final flight-enable interlock silently does not exist.
13. **DFU jumper left on the board or working loose.** `J2 pin 5 = 3V3` is next to `pin 6 = BOOT0`, BOOT0's VIH is only 1.16 V, and firmware cannot read BOOT0 — the board just fails to boot. The LEDs are invisible in a closed bay; the only detector is the buzzer.
14. **Counterfeit / relabelled parts** (AO3400A, AON6403, ICM-45686, USBLC6, MS5611, AP63203). The probability is kept low by "the C number is the brand choice" (relabels are different SKUs), but an AO3400A error covers the entire "inserting the arming plug cannot self-fire" argument.
15. **Mechanical failure of the two Ø8 × 10 mm polymer cans + the screw terminals** — from **landing shock** (92–367 g on a 2 g cantilever with its centre of mass 5.5 mm up, standing on two terminations) and **deployment pull**, not vibration fatigue.
16. **The VCAP 2.2 µF X5R falls out of ST's window at 85 °C**: 2.2 × 0.90 (tolerance) × 0.85 (X5R temperature) × 0.95 (ageing) = 1.60 µF < ST's 1.76 µF minimum, and it happens when the die is hottest. Both VCAPs degrade together, no redundancy. *Temperature/ageing factors are generic values; Samsung's actual curves not checked.*
17. **Document / reference / dimension inconsistencies causing ordering errors** ((j)(k)(l) above).
18. **LC peaking near the buck's PFM burst frequency**: the soft-start argument holds (ωn·T = 2π · 12800 · 0.004 = 322, residual ramp overshoot about 0.6 % ≈ 20 mV, no threat to 3.6 V), but **soft start does not govern light-load PFM bursts**, whose repetition rate at tens of mA falls in the kHz range and can sit on the 12.8 kHz resonance continuously; Q = 4.8 gives +13.6 dB. The consequence is analog noise on VREF+/sensors, not a dead board.
19. **Black-powder residue surface leakage to the pyro gate — ruling: bought out by the 1k pull-down, recorded and accepted.** Recomputed with the corrected `Vgs(th)` minimum of 0.65 V, it takes a surface-insulation failure of about **12 kΩ** to lift the gate to threshold; real SIR failures are in the megohm range. No parts or process spent on it. *(Superseded by MARGIN_PRESCRIPTION.md §4.13: conformal coating is now mandatory.)*

---
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

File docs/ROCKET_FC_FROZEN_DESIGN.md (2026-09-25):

# Rocket Flight Computer v1 — Frozen Design Document (FROZEN)

Frozen 2026-09-03. This file is the **only** input to schematic capture. Anything not written here does not exist; anything written here may not be "optimized" during drawing.
Optimization target (stated explicitly and repeatedly in the requirements): **the fewer parts the better, the more robust the better.** When in doubt, delete it.

> Superseded in part: the board is now 46 mm wide for a 54.66 mm ID airframe (see `GEOMETRY_REV_G.md`), and the design has become the single-board M3 (see `../STATUS.md`). The electrical rationale below still applies unless a later document overrides it.

---

## 1. Change summary

| Item | Original spec | Changed to | Reason (one line) | Part delta |
|---|---|---|---|---|
| Board size | 40 × 85 mm | **50 × 110 mm** | No terminal arrangement fits a 40 mm edge (B1/B2); a 105 mm long axis has zero margin and three known 1–2 mm creeps (C4) | 0 |
| Stackup copper | 4 layers, 2 oz | **4 layers, 1 oz outer / 1 oz inner** (inner upgraded from JLC's default 0.5 oz) | 2 oz pushes min track/space to 0.15–0.20 mm and annular ring to 0.254 mm; LQFP100 pad gap is only 0.20 mm → the MCU footprint fails DRC. A 1 oz, 40 mm inner plane already carries 17.3 A per IPC-2221 > 12 A peak | 0 |
| Minimum airframe | 54 mm | **75 mm (3 in), coupler ID 72.87 mm** | The largest 40 mm-wide rectangle inside a 50.72 mm ID is only 31.19 mm tall; the stack is 41.6 mm — geometrically impossible (B5) | 0 |
| Power/switch terminals | 5 × 2-pos 5.08 mm screw terminals | **1 × 4-pos (BAT+/BAT−/SW/SW) + 1 × 6-pos (ARM/ARM/PYRO1/PYRO1/PYRO2/PYRO2)** | Five terminals need 50.8–63.5 mm; a 40 mm edge minus M3 holes leaves 26 mm | −3 |
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

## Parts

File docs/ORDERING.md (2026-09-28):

# Ordering M3-ASSY-R2 prototypes (JLCPCB)

**This is a bench-prototype order, not a flight release.** The first boards are for power-up, dummy-load fire tests and servo tests. R2 firmware does not exist yet, and v0.8.1 must not run on R2. Open items are listed in `docs/R2_VERIFICATION.md` §4–5.

## 1. Regenerate and check

```sh
bash tools/check.sh                         # DRC / unconnected / parity / ERC = 0, audit OK
python3 m3_design/check_actuators.py        # safety contract
python3 tools/export_fab.py                 # Gerber zip, BOM, CPL (orientation-corrected)
python3 tools/jlc_stock.py --boards 5       # JLC stock right now; only U6 should be short
```

`export_fab.py` must report both of these:
- `parts without LCSC code: none`
- `CPL rows without a verified JLC orientation correction: none`

## 2. Files to upload

All three files are in `m3_design/assembly_review/fab/`:
- `m3_gerber.zip`: Gerbers and drill files. This one is git-ignored and regenerated by the script.
- `m3_bom_jlc.csv`
- `m3_cpl_jlc.csv`

## 3. PCB options

| Option | Value | Why |
|---|---|---|
| Layers | 4 | F.Cu / In1 GND / In2 3V3 / B.Cu |
| Size | 46 × 238 mm | from the board outline |
| Thickness | 1.6 mm | board setup |
| Outer copper | 1 oz | `ROCKET_FC_FROZEN_DESIGN.md` §1 |
| **Inner copper** | **1 oz (not the 0.5 oz default)** | same; the inner planes carry return current |
| Min track / space | 0.2 / 0.15 mm | board rules |
| Min via | 0.3 mm drill / 0.6 mm pad | board rules |
| Surface finish | ENIG recommended | 0.5 mm LQFP100, LGA-14, QFN / DFN lands |
| Impedance control | not needed | USB FS only |

## 4. Assembly (PCBA)

- Assembly side: **Top**. Every part is on the top. Choose **PCBA with THT assembly** so JLC also fits the terminals and headers; the CPL contains every part, SMD and THT.
- Quantity: JLC assembles at least 2 boards; stock was checked for 5.
- Orientation: the CPL is already corrected per LCSC code. `tools/jlc_orient.py` matched every footprint pad by pad against the LCSC/EasyEDA footprint; the data is in `tools/jlc_easyeda/pads.json` and the results in `tools/jlc_corrections.json`.
  - 8 parts would otherwise have been placed rotated: U7, U8, U10, U11, U12, U13, D121 and LED2. J3 also gets a 0.1 mm position correction.
  - Still confirm in JLC's placement preview. **Check these first:** D9, D120, D122, D123, LED1, LED2, C84 and C121 (polarity); U1–U13 and Q120–Q125 (pin 1); J3 (USB-C position).

**Full PCBA.** JLC can fit every part. The one extra step is U6:

| Part | What to do |
|---|---|
| U6 SAM-M10Q-00B | JLC stock is 0. In the JLC account, add it through **Parts Manager → Global Sourcing** before ordering the PCBA; DigiKey had about 2,600–2,900 in stock on 2026-09-27 (findchips). Alternatively, consign it (ship it to JLC). Either way JLC places it with the rest |
| J1, J9, J120, J121 (DB128V-5.08-4P), J122 (3 × 4), J2 (1 × 6 PZ254V-11-06P), J123 (1 × 2 PZ254V-11-02P) | Through-hole, all in JLC stock: JLC THT assembly |

## 5. Parts changed for availability (2026-09-27)

| Ref | Was | Now | Evidence |
|---|---|---|---|
| U8 | AP63200WU-7 (JLC 0) | AP63300WU-7 C2158012 | Same TSOT26 pinout, VFB 0.8 V, 500 kHz, PFM (Diodes DS42002) |
| L3 | SRP5030TA-100M (JLC 0) | SRP5030T-6R8M C1329837 | Same body and land (Bourns SRP5030T/TA); 6.8 µH per AP63300 Table 1 |
| C77 | 100 pF C0G | 47 pF C0G C1671 | AP63300 Table 1, 5 V row |
| C84 | 25SVPF330M (JLC 2) | 35SVPK330M C178373 | Same OS-CON size code F12 (Panasonic SVPK catalog) |
| R86 | 80 k 0.1 % (not orderable) | 80.6 k 0.1 % C861568 | −0.75 %, inside the TPS2121 ILIM tolerance |
| R84, R9 | no LCSC code / zero stock | C705743, C25915 | exact value |
| J2, J123 | cut from a 1 × 40 strip (JLC cannot cut) | PZ254V-11-06P C492405, PZ254V-11-02P C492401 | same 2.54 mm pitch; orientation matched to the LCSC footprint |

## 6. Off-board parts the vehicle needs (not in this BOM)

| Part | Details |
|---|---|
| Arming plug | Two 5 A fast-acting 5 × 20 fuses (Littelfuse 0217005 class) in a 4-wire plug (`M3_ACTUATOR_MERGE.md` §2.2) |
| Battery lead | In-line 15 A ATO fuse (`MARGIN_PRESCRIPTION.md` P0-3b) |
| Power switch | Sealed reed / magnetic, or dry-circuit-rated with gold contacts (the contact carries about 6.6 µA; `R2_VERIFICATION.md` §4) |
| Servos | HV servos. The + rail is RAW_ACT, 2S up to 8.4 V |

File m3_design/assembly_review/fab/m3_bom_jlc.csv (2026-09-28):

Comment | Designator | Footprint | LCSC Part # | Manufacturer Part | Qty | Assembly
100nF | C5,C13,C14,C15,C16,C17,C18,C21,C24,C29,C30,C31,C32,C33,C160 | C0402 | C1525 |  | 15 | SMT
22uF | C6,C7,C8,C9,C10,C11,C34,C150,C151 | C0805 | C45783 |  | 9 | SMT
2.2uF | C19,C20,C120 | C0603 | C23630 |  | 3 | SMT
1uF | C22 | C0603 | C15849 |  | 1 | SMT
4.7uF | C23,C28 | C0603 | C19666 |  | 2 | SMT
10pF | C25,C26 | C0402 | C32949 |  | 2 | SMT
10nF | C60,C94,C122,C127,C129,C139,C141 | C0603 | C57112 |  | 7 | SMT
4.7nF 50V C0G 5% | C70,C81 | C_0603_1608Metric | C85980 | GRM1885C1H472JA01D | 2 | SMT
100nF 50V X7R 10% | C71,C74,C83,C90,C93,C128,C140 | C_0603_1608Metric | C1591 | CL10B104KB8NNNC | 7 | SMT
22uF 25V X7R 10% | C72,C73,C75,C76,C82,C92 | M3_GRM32_1210 | C21397 | GRM32ER71E226KE15L | 6 | SMT
47pF 50V C0G 5% | C77 | C_0603_1608Metric | C1671 | CL10C470JB8NNNC | 1 | SMT
1uF 50V X7R 10% | C80,C91 | C_1206_3216Metric | C1848 | CL31B105KBHNNNE | 2 | SMT
330uF 35V | C84 | M3_OSCON_F12 | C178373 | 35SVPK330M | 1 | SMT
470nF 25V X7R 10% | C85 | C_0603_1608Metric | C1623 | CL10B474KA8NNNC | 1 | SMT
1uF 25V X7R 10% | C86 | C_0603_1608Metric | C29936 | CL10B105KA8NNNC | 1 | SMT
470uF 25V | C121 | CAP-SMD_BD8.0-L8.3-W8.3-LS9.0-FD_H10.5 | C46550466 | MA25V470M8x10 | 1 | SMT
220nF 25V X7R | C126,C138 | C0603 | C21120 | CL10B224KA8NNNC | 2 | SMT
USBLC6-2SC6 | D4 | SOT-23-6_L2.9-W1.6-P0.95-LS2.8-BL | C7519 |  | 1 | SMT
SMBJ9.0CA | D8 | D_SMB | C135111 | SMBJ9.0CA-13-F | 1 | SMT
B340A-13-F | D9 | D_SMA | C85098 | B340A-13-F | 1 | SMT
BAT54A | D120 | SOT-23-3_L2.9-W1.3-P1.90-LS2.4-BR | C8591 | BAT54A | 1 | SMT
SRV05-4 | D121 | SOT-23-6_L2.9-W1.6-P0.95-LS2.8-BL | C13612 | SRV05-4.TCT | 1 | SMT
BAT54S | D122 | SOT-23-3_L2.9-W1.3-P1.90-LS2.4-BR | C47546 | BAT54S,215 | 1 | SMT
1N5819WS | D123 | SOD-323_L1.8-W1.3-LS2.5-RD | C191023 | 1N5819WS | 1 | SMT
BAT+ / GND / SW / SW | J1 | M3_DB128V_4P_Entry | C2915641 |  | 1 | THT (JLC THT assembly)
SWD+DFU 1x6 | J2 | HDR-TH_6P-P2.54-V-M-1x6 | C492405 | PZ254V-11-06P | 1 | THT (JLC THT assembly)
USB-C 2.0 | J3 | USB-C_SMD-TYPE-C-31-M-12_1 | C165948 |  | 1 | SMT
CAM 5V / GND / RX / TX | J9 | M3_DB128V_4P | C2915641 |  | 1 | THT (JLC THT assembly)
ARM: RAW / BUS2 / BUS1 / RAW | J120 | M3_DB128V_4P | C2915641 |  | 1 | THT (JLC THT assembly)
E1- / E1+ / E2+ / E2- | J121 | M3_DB128V_4P | C2915641 |  | 1 | THT (JLC THT assembly)
SERVO 3x4 | J122 | HDR-TH_12P-P2.54-V-M-R3-C4-S2.54 | C32713291 |  | 1 | THT (JLC THT assembly)
PULL-PIN 1x2 | J123 | M3_PULLPIN_1x2 | C492401 | PZ254V-11-02P | 1 | THT (JLC THT assembly)
4.7uH | L1,L2 | IND-SMD_L4.0-W4.0 | C57269 |  | 2 | SMT
6.8uH | L3 | M3_SRP5030TA | C1329837 | SRP5030T-6R8M | 1 | SMT
RED | LED1 | M3_NCD0805R1_K1 | C84256 | NCD0805R1 | 1 | SMT
YEL | LED2 | M3_KT0805Y_A1 | C2296 | KT-0805Y | 1 | SMT
MLT-8530 | LS120 | BUZ-SMD_4P-L8.5-W8.5-P8.50-BR | C94599 | MLT-8530 | 1 | SMT
AON6403 | Q120,Q121 | PDFN-8_L5.6-W5.2-P1.27-LS6.1-BL | C2760089 | AON6403 | 2 | SMT
AO3400A | Q122,Q123 | SOT-23-3_L2.9-W1.3-P1.90-LS2.4-BR | C20917 | AO3400A | 2 | SMT
AON7524 | Q124,Q125 | M3_AON7524_DFN3x3A | C431195 | AON7524 | 2 | SMT
10k | R5,R10,R11,R61,R62,R63,R64,R104,R121,R124,R128,R129,R131,R132,R140,R141,R143,R144,R154,R155,R156,R157,R161,R163 | R0402 | C25744 |  | 24 | SMT
5.1k | R7,R8 | R0402 | C25905 |  | 2 | SMT
6.2k 1% | R9 | R0402 | C25915 | 0402WGF6201TCE | 1 | SMT
4.7k | R12,R13,R125 | R0402 | C25900 |  | 3 | SMT
220R | R32,R33,R126,R138,R162 | R0805 | C17557 |  | 5 | SMT
100k | R60,R120,R122,R123 | R0402 | C25741 |  | 4 | SMT
1.78k 0.1% | R70 | R_0603_1608Metric | C861207 | RT0603BRD071K78L | 1 | SMT
172k 0.1% | R71 | R_0603_1608Metric | C861162 | RT0603BRD07172KL | 1 | SMT
30.9k 0.1% | R72 | R_0603_1608Metric | C861313 | RT0603BRD0730K9L | 1 | SMT
1k 1% | R74,R77,R100,R101,R103 | R_0603_1608Metric | C22548 | RC0603FR-071KL | 5 | SMT
10k 0.1% | R75,R76,R78,R88,R89,R90,R91,R92,R102,R110 | R_0603_1608Metric | C95204 | RT0603BRD0710KL | 10 | SMT
1M 0.1% | R80 | R_0603_1608Metric | C326730 | RT0603BRD071ML | 1 | SMT
280k 0.1% | R81 | R_0603_1608Metric | C705755 | RT0603BRD07280KL | 1 | SMT
2M 0.1% | R82 | R_0603_1608Metric | C4241878 | MCT0603MD2004BP500 | 1 | SMT
300k 0.1% | R83 | R_0603_1608Metric | C705762 | RT0603BRD07300KL | 1 | SMT
1.65k 0.1% | R84 | R_0603_1608Metric | C705743 | RT0603BRD071K65L | 1 | SMT
66.5k 1% | R85 | R_0603_1608Metric | C137691 | RC0603FR-0766K5L | 1 | SMT
80.6k 0.1% | R86 | R_0603_1608Metric | C861568 | RT0603BRD0780K6L | 1 | SMT
44.2k 0.1% | R87 | R_0603_1608Metric | C861410 | RT0603BRD0744K2L | 1 | SMT
1k | R105,R127,R130,R133,R139,R142,R145,R160 | R0402 | C11702 |  | 8 | SMT
2R 1% 2W pulse | R134,R135 | R2512 | C3013496 | CRM2512-FX-2R00ELF | 2 | SMT
1k 0805 | R150,R151,R152,R153 | R0805 | C17513 | 0805W8F1001T5E | 4 | SMT
STM32H743VIT6 | U1 | LQFP-100_L14.0-W14.0-P0.50-LS16.0-BL | C5271084 |  | 1 | SMT
AP63203WU-7 | U2 | TSOT-26_L2.9-W1.6-P0.95-LS2.8-BL | C780769 |  | 1 | SMT
W25Q128JVSIQ | U3 | SOIC-8_L5.3-W5.3-P1.27-LS8.0-BL | C97521 | W25Q128JVSIQ | 1 | SMT
ICM-45686 | U4 | LGA-14_L3.0-W2.5-P0.50-TL | C22459454 |  | 1 | SMT
MS561101BA03 | U5 | SENSORS-SMD_MS5611-01BA03 | C15639 |  | 1 | SMT
SAM-M10Q-00B | U6 | LCC-20_L15.5-W15.5-P1.90_SAM-M10Q-00B | C5443880 | SAM-M10Q-00B | 1 | Consign or JLC Global Sourcing: SAM-M10Q-00B from DigiKey (JLC stock 0 on 2026-09-27)
TPS259570DSGR | U7 | M3_TPS2595_DSG | C1849463 |  | 1 | SMT
AP63300WU-7 | U8 | M3_AP63200_TSOT26 | C2158012 | AP63300WU-7 | 1 | SMT
TPS259470LRPWR | U9 | M3_TPS25947_RPW | C3662793 |  | 1 | SMT
TPS2553DBVR | U10 | M3_TPS2553_DBV | C55266 |  | 1 | SMT
TPS2121RUXR | U11 | M3_TPS2121_RUX | C485916 |  | 1 | SMT
TXU0202DCUR | U12 | M3_TXU0202_DCU | C5186957 | TXU0202DCUR | 1 | SMT
TPS70933DBVR | U13 | M3_TPS709_DBV | C89347 | TPS70933DBVR | 1 | SMT
25MHz CL8pF | Y1 | CRYSTAL-SMD_4P-L3.2-W2.5-BL | C1985619 |  | 1 | SMT

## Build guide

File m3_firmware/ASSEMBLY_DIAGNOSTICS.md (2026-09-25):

# M3-ASSY-R1 bench diagnostics v0.8.1

This version binds to `m3_design/assembly_review/m3.kicad_pcb`, SHA256 `e432d3436d5029de0a74a4b0ebcd02ec092dedf6d4252ce310f7be301558627f`. After the LED assembly fix it was rebuilt for the exact board ID; production C / headers and GPIO roles are unchanged from v0.8; no flight or actuation functions were added.

| Image directory | External flash | Camera behaviour |
|---|---|---|
| build_assembly_inspect | Read-only check | Off by default |
| build_assembly_record | Explicitly appends diagnostic records, no erase / overwrite | Off by default |
| build_assembly_inspect_query | Read-only check | One information query, then power left on |
| build_assembly_record_query | Explicit append, no erase / overwrite | One information query, then power left on |

All four images provide raw sensor / GNSS bench observation, a 1024-byte snapshot, read-only USB download and power FAULT/ST input history. It is still ~1 Hz bench recording; camera recording, real USB enumeration, and real dynamic supply / RF / environmental performance were not verified by the rebuild. For interpretation of the power status and its sampling limits see [the v0.8 notes](POWER_STATUS_DIAGNOSTICS.md) (its old build directories are historical only).

The host accepts two explicit wire-v8 configurations: M3-PDIAG-R1 and M3-ASSY-R1. It checks the board SHA, build SHA, protocol, CRC and sample times; a matching wire version alone cannot pass a wrong board ID. On disconnect it keeps the failure and the prefix already read, never fabricating normal readings. No physical board or probe was connected and nothing was flashed.

With a confirmed device attached, use a new output path that does not yet exist:

```sh
diagnostics/.venv/bin/python -m diagnostics.usb capture \
  --port /dev/cu.YOUR_DEVICE --assembly BOARD_001 \
  --manifest m3_firmware/build_assembly_inspect/manifest.json \
  --out diagnostics/runs/board001_assembly.json
```

Log export still uses `diagnostics.usb dump` with the same manifest and an explicit `--sectors`. Only run against a device you have specified; verification only opened a randomly generated, non-existent serial path to confirm it returns CONNECTION_FAILED rather than fabricated measurements.

`verify_assembly_firmware.py` re-checks the four ARM binaries, input files and test logs by hash, including old-version compatibility, production C with a scripted HAL, a wrong board ID with the same wire version, fault history, disconnect and no-device tests. All of this is software or file evidence; `hardware_tested`, `flashed` and `full_m3_complete` remain false. (The verification run directory is regenerated locally and is not stored in the repository.)

Re-check with: `diagnostics/.venv/bin/python m3_firmware/verify_assembly_firmware.py`. Any rebuild must first keep the old build, and after any schematic / PCB / footprint change must pass native checks and re-binding again — never edit the manifest by hand to fake compatibility.

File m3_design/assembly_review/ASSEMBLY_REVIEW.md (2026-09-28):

# M3-ASSY-R2 — actuator merge (current)

2026-09-25. R2 adds the actuator power switch, dual independently fused pyro channels with a complete arming break, four servo outputs, the launch pull-pin and the buzzer to R1, on a 46 × 238 mm board (208 positions, 183 fitted parts, 25 test pads, 14 sheets; R134/R135 and the 10 k cold pull-ups added 2026-09-27, see §2.6 of the design record; CAM_5V sense R104/R105/C94 added 2026-09-28). Design rationale, datasheet evidence, routing method and the open verification list: [docs/M3_ACTUATOR_MERGE.md](../../docs/M3_ACTUATOR_MERGE.md). `top.png`, `bottom.png`, `drc.json`, `erc.json`, `schematic.net.xml` and `sheets/` are regenerated for R2. The R1 evidence files (`verification_assembly.json`, `visual_review.json`, `bom_review.json`, `visual_inputs.json`) are kept as the R1 record; they are bound to the R1 hash and do not describe R2. Manufacturing files: `fab/` (from `tools/export_fab.py`).

---

# M3-ASSY-R1 assembly correction review

2026-09-08. This revision is still a bench candidate: one 46 × 186 mm four-layer board for ordinary power / acquisition / logging / camera interface / bench diagnostics. 135 footprint positions: 115 nominally fitted parts and 20 test points. It does not implement every rocket function in the requirements; the full gap list is in [the requirement status](../../STATUS.md).

Open `m3.kicad_pro`. PCB SHA256: `e432d3436d5029de0a74a4b0ebcd02ec092dedf6d4252ce310f7be301558627f`.

## Assembly discrepancies confirmed and corrected

| Ref | Purchased identity and evidence | Handling in this revision |
|---|---|---|
| LED1 | NATIONSTAR NCD0805R1, LCSC C84256; maker drawing p. 2, cathode = pin 1 of this drawing | Dedicated footprint M3_NCD0805R1_K1; 0.8 × 1.2 mm lands at ±0.85 mm centres, 0.90 mm inner gap; its own cathode silkscreen |
| LED2 | KENTO KT-0805Y, LCSC C2296; maker drawing p. 2 states pin 1 positive, pin 2 negative | Dedicated footprint M3_KT0805Y_A1; 1.0 × 1.4 mm lands at ±0.95 mm centres, 0.90 mm inner gap; cathode on the other end |
| U3 | Winbond W25Q128JVSIQ, LCSC C97521; Rev G package drawing, PDF p. 68 / printed p. 67 | The 208 mil SOIC choice is correct; maker and part-number fields completed; not replaced with a narrow-body package |

The old generic LED land had centres at ±1.10 mm and 1.0 × 1.25 mm pads, matching neither maker's recommended drawing. The two LEDs' pin numbers and nets were not swapped; their genuinely different cathode numbering is expressed through different footprints.

All three references use consistent Manufacturer / Manufacturer Part / LCSC fields in the PCB, schematic and per-reference BOM. All 2201 original tracks and vias, every other part's pads and position, net assignments and pour boundaries are unchanged. The only copper-shape change is the four LED pads, with fills regenerated. Two old revision labels on the top silkscreen were changed to ASSY-R1 so a physical board cannot be confused with the host diagnostic revision.

## What the 3D models mean

The LEDs use their maximum-size envelopes: LED1 2.1 × 1.3 × 0.7 mm; LED2 2.1 × 1.35 × 0.95 mm. A green bar marks the cathode; the mesh splits the body and bar into adjacent solids so the bar doesn't coincide with the top face and vanish in native renders. They are locally created orientation and size envelopes, **not maker STEP files and not physical assembly verification**. All other retained models have the same evidence boundary.

`top.png` and `bottom.png` are native renders of the saved PCB; `led_native_closeup.png` is a crop of the top render; `led_detail.png` is read back from the saved pads to check local coordinates and polarity. `visual_review.json` records the hashes of the images actually reviewed.

## Checks and firmware

`verification_assembly.json` binds the saved PCB, the ten schematic sheets, the maker PDFs, the library files and the models. Native all-severity DRC, unconnected items, schematic parity and ERC are all zero; nothing passed by ignoring violations. There were also negative tests for wrong pads, wrong polarity, wrong model rotation, wrong part number, old silkscreen labels and copper changes.

[Diagnostic firmware v0.8.1](../../m3_firmware/ASSEMBLY_DIAGNOSTICS.md) was rebuilt against this revision's exact PCB hash; its production C and headers are unchanged from PDIAG v0.8. Both share wire encoding v8, but the host tools verify board ID and build identity separately, so an old image cannot pass as compatible with the new board.

Reference Gerbers, drill files, the 115 fitted positions and the BOM were produced with the review. Purchasing stock, rotation conventions for assembly, the remaining footprints, harness mounting, real electrical dynamics and whole-board function are not yet accepted, so this is not a manufacturing release package.

## Maker documents

- [NATIONSTAR NCD0805R1 datasheet, p. 2](https://datasheet.lcsc.com/datasheet/pdf/e3e35db60c068efe42b02d21fe498cf3.pdf?productCode=C84256): envelope and recommended land; [purchased identity C84256](https://www.lcsc.com/product-detail/C84256.html).
- [KENTO KT-0805Y datasheet, p. 2, 2018-12-06](https://datasheet.lcsc.com/datasheet/pdf/3f6a14f9ea2fc39f6e05d2ab0fa53e2b.pdf?productCode=C2296): pin polarity numbering, envelope and recommended land; [purchased identity C2296](https://www.lcsc.com/product-detail/C2296.html).
- [Winbond W25Q128JV Rev G, 2019-04-08](https://www.winbond.com/resource-files/w25q128jv%20revg%2004082019%20plus.pdf): 208 mil package drawing and ordering codes; [purchased identity C97521](https://www.lcsc.com/product-detail/C97521.html).

The PDFs themselves are not in this repository (download them from the links); their SHA256 hashes are in `sources.json`, and the extracted drawing images are in `sources/`. These drawings were used for this dimension / polarity check; they are not a current stock check, a supply-chain lock or a full electrical re-qualification of the parts.

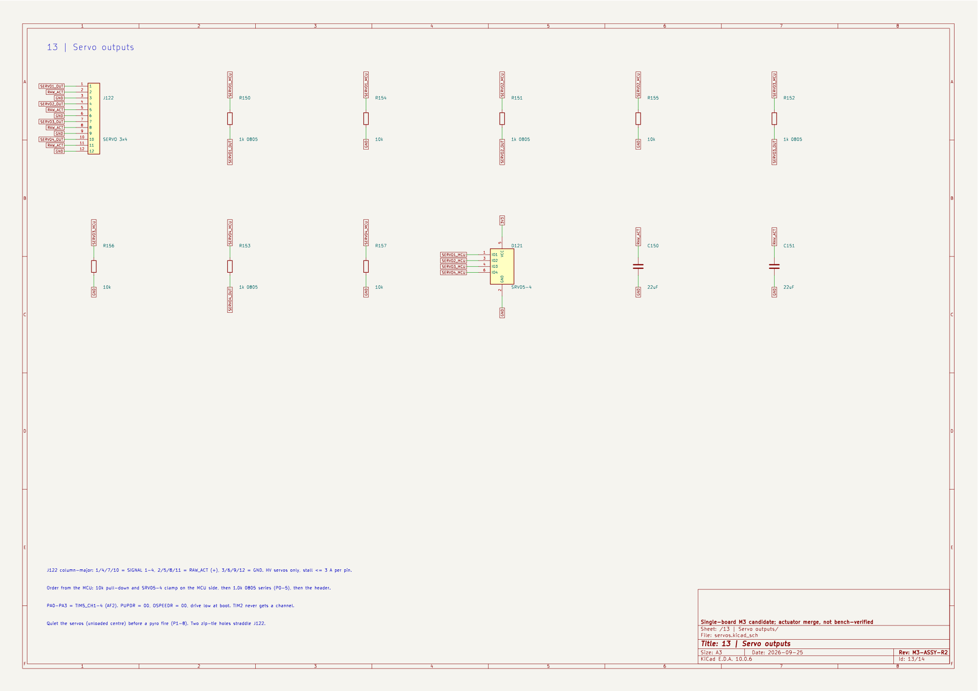
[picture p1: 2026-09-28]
m3_design/assembly_review/sheets/m3-13 | Servo outputs.png

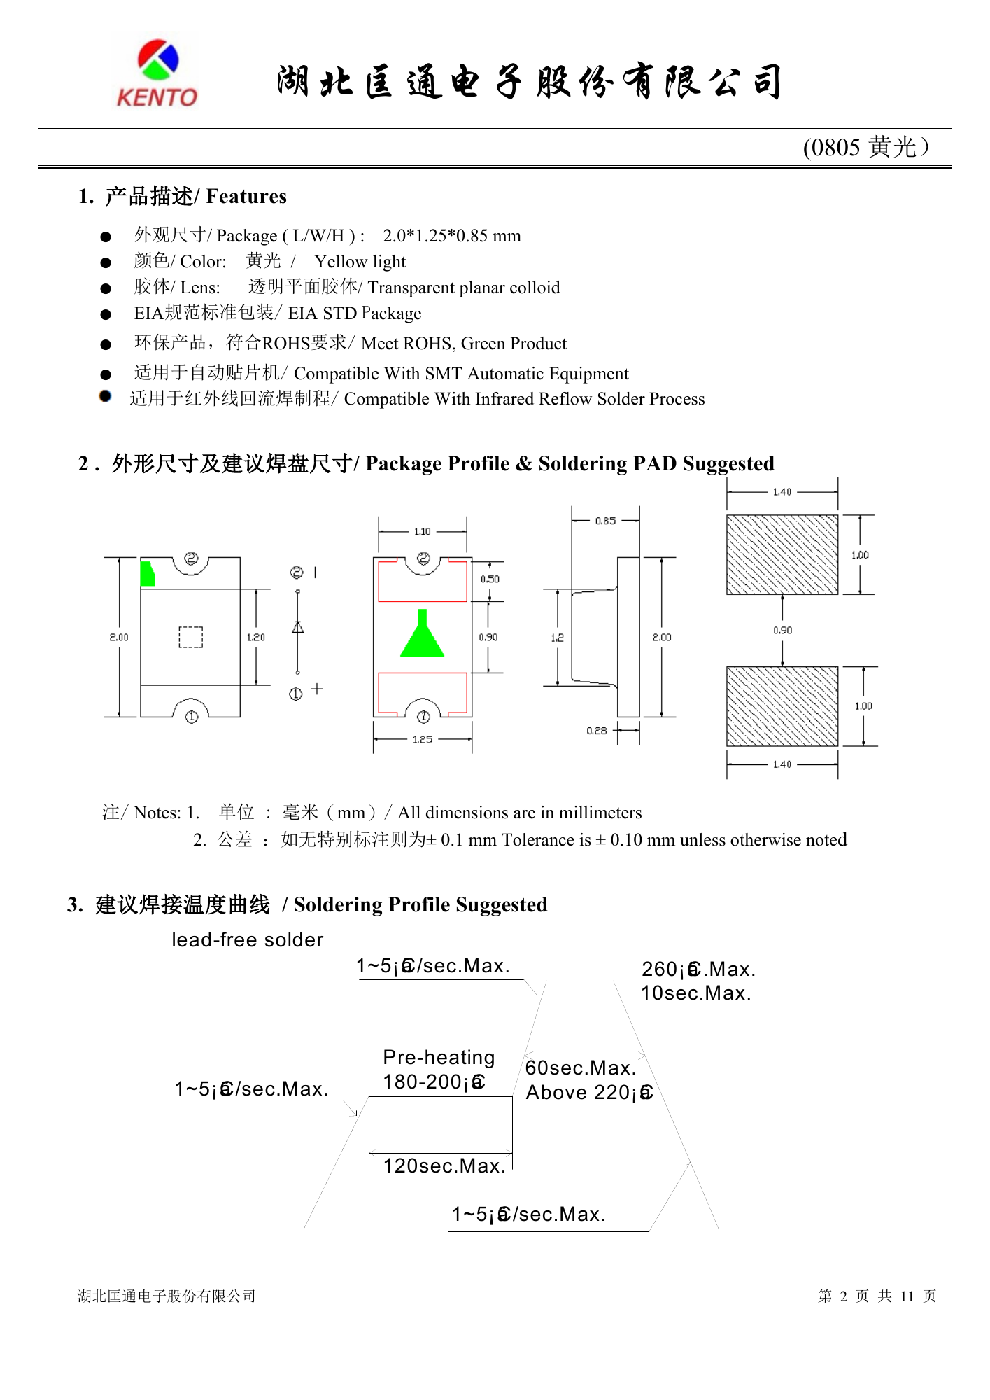
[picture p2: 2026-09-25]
m3_design/assembly_review/sources/kt_0805y_drawing.png

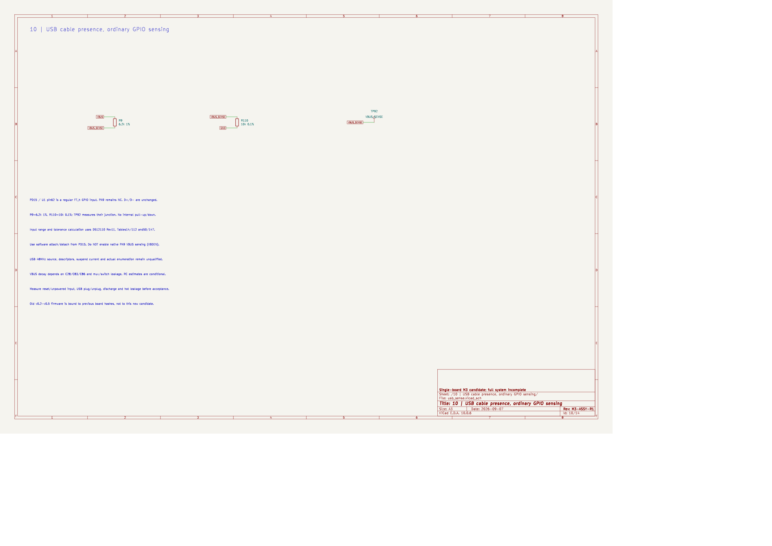
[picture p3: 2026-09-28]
m3_design/assembly_review/sheets/m3-10 | USB cable presence, ordinary GPIO sensing.png

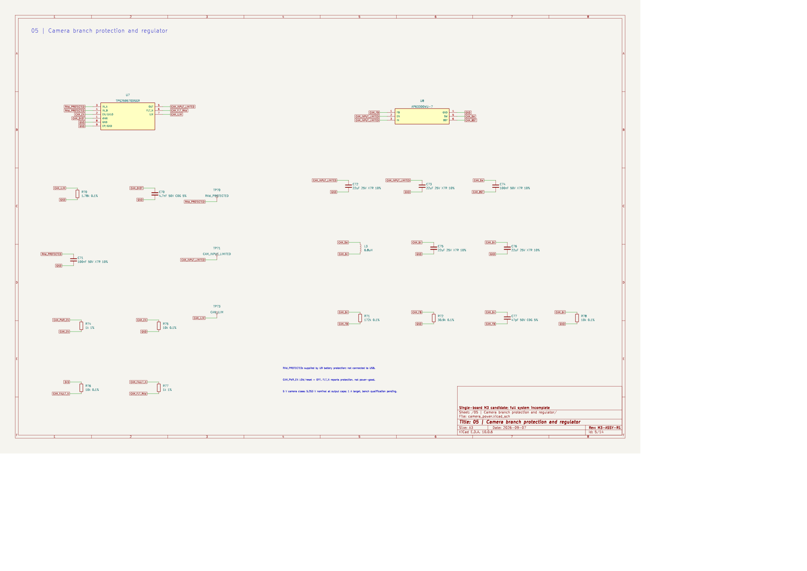
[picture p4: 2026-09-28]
m3_design/assembly_review/sheets/m3-05 | Camera branch protection and regulator.png

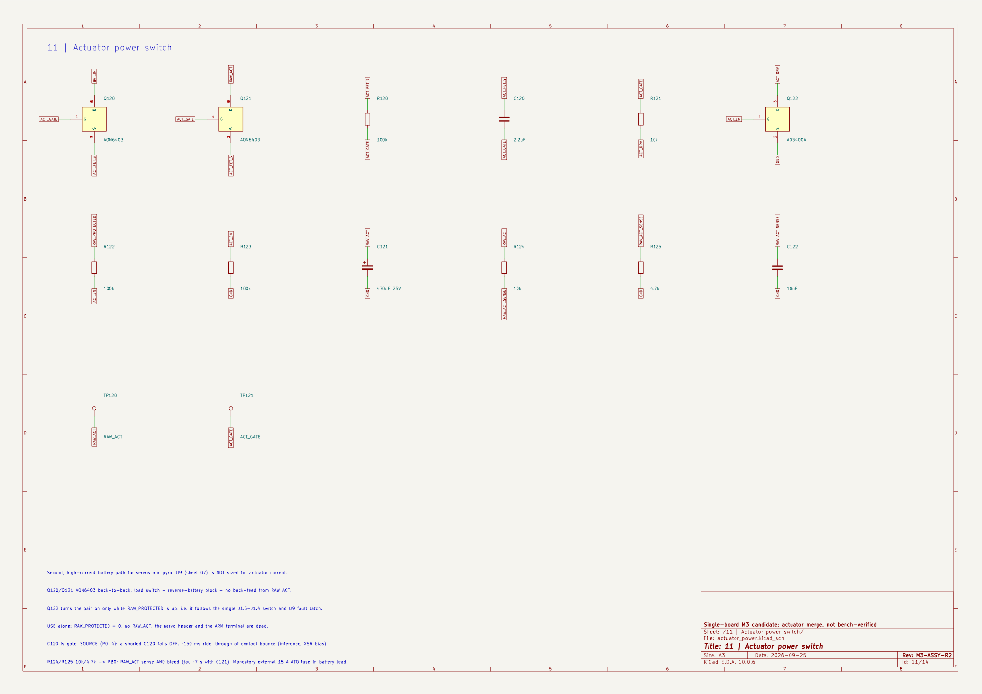
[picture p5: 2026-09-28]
m3_design/assembly_review/sheets/m3-11 | Actuator power switch.png

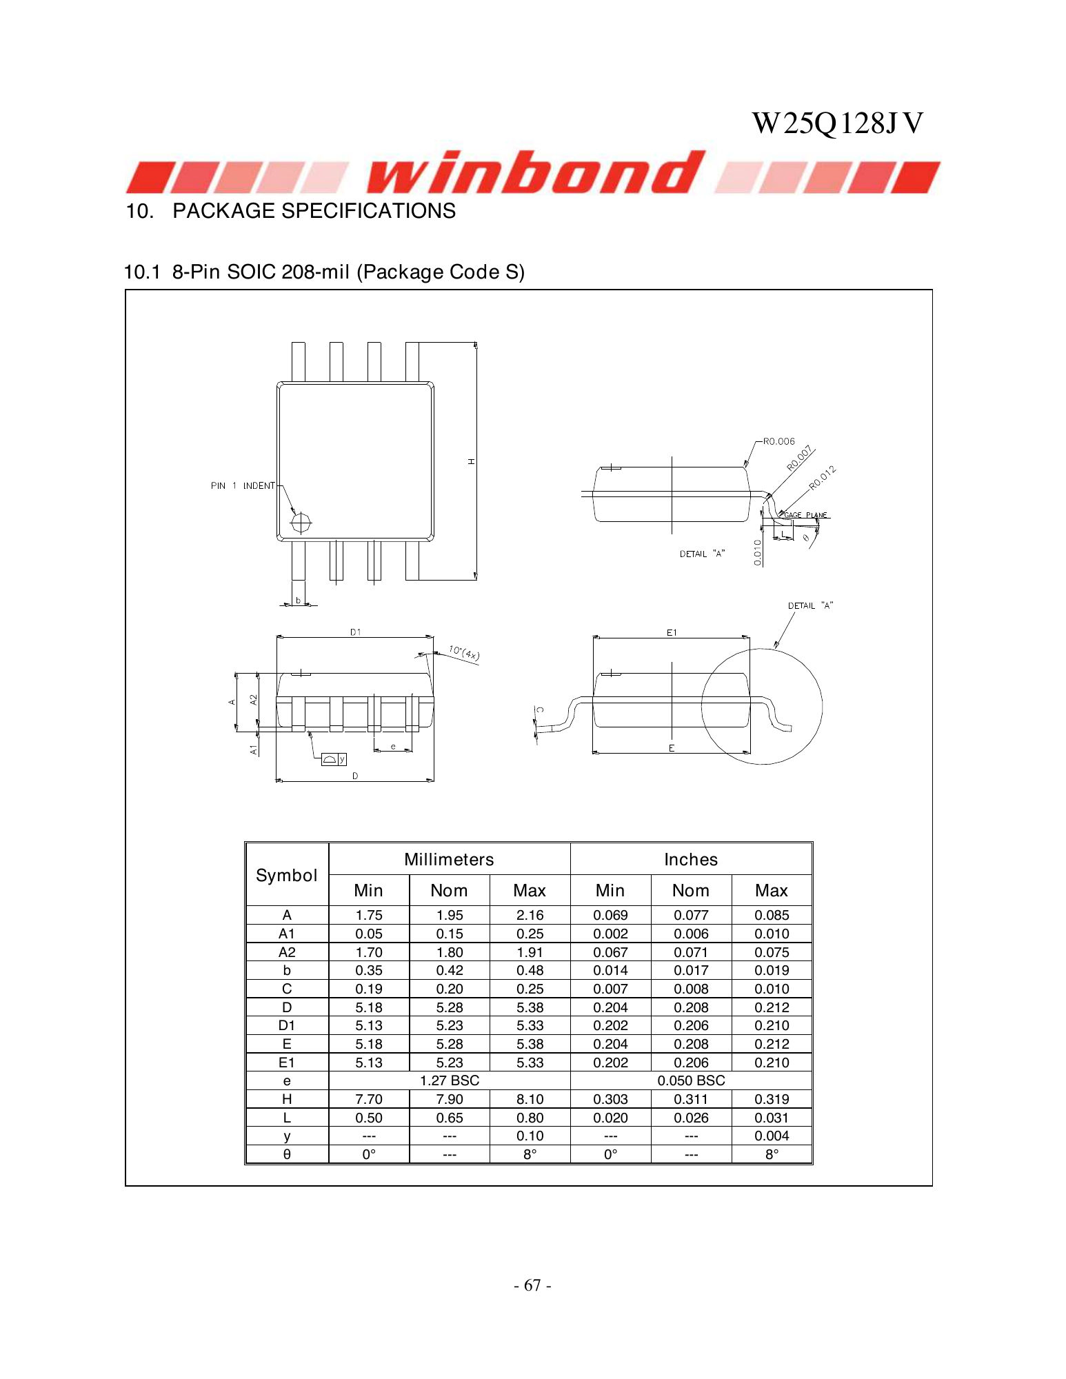
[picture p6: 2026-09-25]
m3_design/assembly_review/sources/w25q128jv_revg_drawing.png

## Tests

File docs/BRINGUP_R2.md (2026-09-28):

# M3-ASSY-R2 first power-up (bench)

Do these steps in order on each new board. **Stop at the first step that fails**, and record the reading with the board ID. Nothing in this document needs R2 firmware. The MCU is blank from the factory. **Do not flash v0.8.1** (it is R1 firmware).

Equipment:
- current-limited bench supply
- multimeter
- USB-C cable with a current meter
- ST-LINK (or any SWD probe)

For the first power-ups, have **no igniter, no arming plug, no servo, no camera** connected.

Test-point positions (x, y in mm, top view, origin at the J1 battery end):

| Test point | Net | Position |
|---|---|---|
| TP80 | BAT_IN | 8.5, 8.5 |
| TP84 | BAT_ENABLE | 7, 18 |
| TP85 | BAT_FAULT_N | 7, 23 |
| TP88 | GND | 7, 28 |
| TP87 | LOGIC_SOURCE_ST | 10, 30 |
| TP82 | USB_LIMITED | 42, 12 |
| TP86 | USB_FAULT_N | 42, 17.5 |
| TP83 | VLOGIC | 41, 20 |
| TP89 | BAT_ILIM | 24, 13.5 |
| TP81 | RAW_PROTECTED | 23, 31 |
| TP121 | ACT_GATE | 16.8, 35.5 |
| TP120 | RAW_ACT | 42.5, 36.4 |
| TP123 | PYRO2_GATE | 26.6, 49.1 |
| TP124 | GND | 17.9, 58 |
| TP122 | PYRO1_GATE | 26.6, 64 |
| TP71 | CAM_INPUT_LIMITED | 29, 101 |
| TP72 | CAM_5V | 33, 121 |
| TP90 | CAM_IO_3V3 | 17, 146 |
| TP92 | VBUS_SENSE | 18, 180.5 |

3V3 is on **J2 pin 5**; J2 pin 1 is GND.

## 0. Unpowered

Measure resistance to GND on each rail:

| Rail | Measure at | Expected |
|---|---|---|
| BAT_IN | TP80 | no short, above about 1 kΩ (TVS and dividers) |
| VLOGIC | TP83 | no short |
| 3V3 | J2.5 | no short |
| RAW_ACT | TP120 | no short, about 15 kΩ (R124 + R125) |

A reading under about 10 Ω on any rail: **stop**. Look for solder bridges and parts placed the wrong way round (preview checklist, `ORDERING.md` §4).

## 1. USB only (battery disconnected)

Plug USB-C in through the current meter. With a blank MCU, expect a small draw. **Above 200 mA: unplug.**

| Point | Expected | Derivation |
|---|---|---|
| TP92 VBUS_SENSE | ≈ 3.09 V | 5.0 V × 10k / (6.2k + 10k) |
| TP82 USB_LIMITED | ≈ 5.0 V | TPS2553 on |
| TP86 USB_FAULT_N | ≈ 3.3 V (high = no fault) | pull-up |
| TP83 VLOGIC | ≈ 4.9–5.0 V | TPS2121 selects USB |
| J2.5 3V3 | 3.30 V ± 3 % | AP63203 fixed 3.3 V |
| TP81 RAW_PROTECTED, TP120 RAW_ACT | ≈ 0 V | no battery |
| TP122 / TP123 pyro gates | 0 V | pull-downs, MCU blank |
| TP72 CAM_5V, TP90 CAM_IO_3V3 | 0 V | camera off by default |

## 2. SWD

Connect the probe to J2: pin 1 GND, pin 5 3V3 reference, SWDIO/SWCLK, NRST on pin 4, BOOT0 on pin 6. Leave BOOT0 open.

Read the device ID:

```sh
pyocd cmd -t stm32h743xx -c "read32 0x5C001000"
```

Expected: DBGMCU_IDCODE `0x...450`, the H743 device ID. This proves the MCU, its supply, reset, VCAP and debug path are working.

## 3. Battery input (USB unplugged)

- Bench supply at **7.4 V, current limit 0.3 A**, into J1 BAT+/GND.
- External switch **open** (J1.3–J1.4 not bridged):

  | Point | Expected |
  |---|---|
  | TP80 BAT_IN | 7.4 V |
  | TP84 BAT_ENABLE | 0 V |
  | TP81 RAW_PROTECTED | 0 V |
  | TP120 RAW_ACT | 0 V |
  | TP121 ACT_GATE | ≈ 6.8 V (gate held near the source) |
  | Supply current | ≈ tens of µA |

- **Bridge J1.3–J1.4** (switch closed):

  | Point | Expected | Derivation |
  |---|---|---|
  | TP84 BAT_ENABLE | ≈ 1.62 V | 7.4 × 280k / 1.28M; UVLO rising at 1.20 V ↔ 5.49 V battery |
  | TP81 RAW_PROTECTED | ≈ 7.4 V | |
  | TP83 VLOGIC | ≈ 7.4 V | highest-voltage source |
  | J2.5 3V3 | 3.30 V | |
  | TP85 BAT_FAULT_N | ≈ 3.3 V | |
  | TP121 ACT_GATE | ≈ 0.67 V | 7.4 × 10k / 110k; the actuator switch is on |
  | TP120 RAW_ACT | ≈ 7.4 V | |

- **UVLO check:** lower the supply slowly. RAW_PROTECTED must switch off at about 5.0 V (falling threshold 1.09 V ↔ 4.98 V). Raise it again; it comes back at about 5.5 V.
- **Reverse polarity check** (optional, only with a current-limited supply): set −7.4 V at 0.1 A. The current must stay near zero and nothing may warm.

## 4. With firmware (R2 bring-up image — to be written)

1. ADC readings compared with the multimeter:
   - VLOGIC_SENSE, V3V3_SENSE, RAW_ACT_SENSE, VBUS_SENSE, CAM_5V_SENSE (PB1, ÷11);
   - PYRO1/2_CONT and ARM1/2_SENSE, plug out. Expected plug-out values are in `m3_design/sim_r2/RESULTS.md` §E:

     | State | Ratiometric reading |
     |---|---|
     | Shorted FET | 0 mV |
     | Good igniter | 95–100 mV |
     | Open igniter | 141–148 mV |

2. IMU WHO_AM_I, barometer PROM CRC, flash JEDEC ID, GNSS NMEA on USART6, USB CDC enumeration.
3. Camera branch: enable CAM_PWR_EN; CAM_5V should read ≈ 5.25 V and CAM_IO_3V3 ≈ 3.3 V.
4. Actuators, in this order and **only with dummy loads**:
   1. Servo PWM with one servo.
   2. Buzzer.
   3. Pull-pin input.
   4. Pyro:
      - use 1 Ω / 5 W dummy loads, not igniters;
      - insert the arming plug last;
      - fire 20 ms per channel;
      - watch that BAT_IN stays above 5 V (`M3_ACTUATOR_MERGE.md` §4 lists the full bench list: plug-insertion test ×20, cold pull-up table, stall thermal).

Record every reading in the board's log. Only after all of this is a board a candidate for anything beyond the bench.

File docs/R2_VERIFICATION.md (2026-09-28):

# M3-ASSY-R2 — verification record (2026-09-27)

This record answers three questions for the current board:
1. Does it meet the requirements?
2. Where is it redundant, and where is it not?
3. Is every footprint, pinout and part number right?

It is CAD, datasheet and simulation evidence only. **No board has been built or measured.**

## 1. Requirements

The governing requirements are the original brief as recorded in `ROCKET_FC_FROZEN_DESIGN.md` §1, the table in `STATUS.md`, the functions in `AGENTS.md` §1 and the safety rules in `AGENTS.md` §2. Items of the original brief that were dropped are dropped with a written reason in the frozen design: microSD, ADXL375, LoRa, LSE, RGB LED, BOOT/reset buttons, and the 40 × 85 mm size. None was dropped silently.

| Requirement | Status on R2 | Evidence |
|---|---|---|
| One board, 2S supply, switch, reverse / over-voltage / current protection, logic hold-up | Implemented | `STATUS.md`, `tools/check.sh` |
| STM32H743, IMU, barometer, QSPI log, GNSS, USB, SWD, camera terminal | Implemented; U1 pin map verified pad by pad | §3 below |
| Four servos, actuator switch | Implemented, simulated | `m3_design/sim_r2` (A, F) |
| Dual pyro, single deploy, independent fuses, complete arming break, continuity / arm sense | Implemented, netlist contract, simulated | `m3_design/check_actuators.py`, sim B–E |
| Pull-pin, buzzer, indicators | Implemented, pull-pin chafe simulated | sim G |
| Commercial backup altimeter fully isolated | By ruling (2026-09-25); nothing on the board | `M3_ACTUATOR_MERGE.md` §1 |
| Safety rule 1: the ARM plug is a complete break | Holds. With the plug out, no copper, part or test point joins RAW_ACT to a bus | `check_actuators.py` rule 1 |
| Safety rule 2: pyro bus after the load switch | Holds. The buses are fed only from RAW_ACT, which is the drain of Q121 | rule 3 |
| Safety rule 4: gate pull-down, series R and gate-source C, off in reset | Holds | rule 4; sim D |
| Manufacturing package | BOM, CPL and Gerbers generated; every line has an LCSC code | `tools/export_fab.py` |

## 2. Redundancy

**Independent per channel:**
- arming-plug fuse and fused bus (FMEA H-5);
- arm sense;
- series current limiter R134 / R135;
- igniter terminal position;
- AON7524 and its gate network;
- continuity divider;
- cold pull-up.

A shorted igniter on one channel no longer affects the other channel or the logic supply (sim C: ≤ 4.1 A, BAT_IN ≥ 5.69 V).

**Shared by both channels** (single-string on the board, accepted in `FMEA_REDUNDANCY.md` §8.2 / V-10). The only backstop is the independent commercial altimeter:

| Shared item | Failure that takes out both channels | Detectable before flight? |
|---|---|---|
| Battery, J1, battery lead, in-line 15 A fuse | Open or flat | Yes (voltage, load step) |
| D8 SMBJ9.0CA | Shorts, which blows the in-line fuse | Yes (board dead) |
| Q120 / Q121 / Q122 actuator switch | Open means no RAW_ACT | Yes (RAW_ACT_SENSE) |
| RAW_ACT net: C121, C150, C151, servo harness | Short means the in-line fuse blows and the whole vehicle is dead | Only if present at power-up; a chafed servo lead in flight is not |
| ARM plug body and J120 | Plug falls out | Yes (ARMx_SENSE); retention is mechanical |
| MCU, firmware, 3V3 / VLOGIC chain, HSE, baro and IMU for apogee | Any single failure | Partly (self-test); FMEA V-1…V-6 |
| PE4 / PE5 adjacent pins | A solder bridge fires both channels together | Yes (H-1 cold test); harmless under single deploy |

**Not made redundant on purpose** (`FMEA_REDUNDANCY.md` §3.3): a second barometer, second IMU, second MCU or buck, or a separate pyro battery.

## 3. Footprints, pinouts, part numbers

All 99 BOM lines / 205 positions were checked against manufacturer datasheets in five groups. Every ISSUE found was fixed in this revision.

| Group | Result | Fixed in this revision |
|---|---|---|
| U1 STM32H743VIT6, 100 pins (ST DS12110 Rev 5, Table 8 and AF tables) | 100/100 OK: pin names, power pins, VCAP, AF of every function, ADC channel and voltage limits, LQFP100 land | — |
| Power ICs and magnetics (AP63203, AP63200, TPS259570, TPS259470L, TPS2553, TPS2121, TPS70933, L1–L3, D8, D9, C84, C121) | 12 OK, 1 ISSUE | C84 had no polarity mark on the top side; added a "+". L1/L2 3D model height was 1.9 mm; set to the real 3.0 mm |
| Signal ICs (W25Q128JVSIQ, ICM-45686, MS5611, SAM-M10Q, TXU0202, Y1, USBLC6, USB-C, LEDs) | 8 OK, 2 ISSUE | BOOT0 ran between the MS5611 pads, against TE p.16 "do not route tracks between pads"; it was rerouted outside the sensor (0/45/90° segments, 4 vias). U12 had no pin-1 mark; added one |
| Actuator discretes and connectors (AON6403, AO3400A, AON7524, BAT54A/S, SRV05-4, 1N5819WS, MLT-8530, DB128V, headers, CRM2512) | 10 OK, 2 ISSUE | The R134/R135 land was the generic 2512; it now uses the Bourns CRM2512 recommended land (2.45 × 3.7 mm pads, 7.6 mm overall), with the parts moved to x 23.6 / y 60.6 and 56.35. The AON7524 3D model was rotated 180°; its pin-1 mark now matches pad 1 |
| Passives (38 lines) | 35 OK, 3 ISSUE | R84 got its LCSC code (C705743). R9 moved to C25915 (UNI-ROYAL 0402WGF6201TCE; the old MPN has zero stock). R86 went from 80 k to **80.6 k** 0.1 % C861568: 80 k was not orderable, and U11's current limit moves by −0.75 %, which is inside the TPS2121's own ILIM tolerance |

**Kept deliberately, with a reason:**
- **U3 must stay W25Q128JV-IQ.** The IQ variant ships with QE fixed at 1, so /WP and /HOLD are data pins and need no pull-ups (Winbond §7.1.4); this closes FMEA H-3 / V-13. An IM variant would reopen the problem.
- The AON6403 land is the generic DFN5x6, not AOS PO-00044. It still covers every lead and the paddle.
- The L1/L2 land differs from Sunlord's recommendation but covers the terminals.
- SRV05-4 row spacing is 2.30 mm against Semtech's 2.50 mm; acceptable.
- U8 is set to 5.25 V on purpose (camera rail).

**Stock (2026-09-27, JLC assembly stock via `tools/jlc_stock.py`).** Every line has enough stock for 5 boards except U6 SAM-M10Q, which must be consigned or bought through Global Sourcing (DigiKey had stock). Parts with zero stock were replaced with verified drop-ins: U8, L3, C77, C84 (`docs/ORDERING.md` §5).

**Placement orientation.** Every CPL row is corrected against the LCSC/EasyEDA footprint of its own LCSC code (`tools/jlc_orient.py`). Without the correction, U7, U8, U10, U11, U12, U13, D121 and LED2 would have been placed rotated.

## 3a. Self-test coverage (AUTOTEST_DESIGN.md)

AUTOTEST_DESIGN's minimum sensing set is on the board:
- VLOGIC → PC2 and 3V3 → PC3, both by divider;
- RAW_ACT → PB0;
- VBUS → PD15;
- per-bus arm sense and per-channel continuity with the cold pull-up (tests T-41 / T-42);
- the internal VREFINT / VBAT / temperature channels;
- the buzzer as a load step (T-16).

R2 adds one sense the original design did not have, for the new camera branch: **CAM_5V → R104 / R105 10k / 1k + C94 → PB1 (ADC12_INP5)**. It reads 0.477 V at 5.25 V and stays at 1.40 V even at the 15.4 V TVS clamp, inside PB1's TT 4.0 V limit. It is live only while the board is powered and the camera branch is on, so it adds no always-live path into an unpowered MCU (AUTOTEST §2.4).

Accepted blind spots, unchanged:
- servo outputs and LEDs;
- BAT+ upstream of the switch (deliberately no divider, AUTOTEST §2.4);
- current sensing (AUTOTEST §3).

## 4. FMEA hardware items (H-1 … H-10) on R2

| Item | Status |
|---|---|
| H-1 cold pull-up + BAT54A | Done (10 k, sim E) |
| H-2 separated gates + sentinels | Done |
| H-3 QSPI /WP /HOLD pull-ups | Not needed: W25Q128JV-IQ (QE fixed 1) |
| H-4 VBUS_SENSE pull-down | Done (R110 of the divider) |
| H-5 two fused buses | Done |
| H-6 physical form / reachability of the ARM plug (V-18) | **Owner decision open.** This is vehicle harness and mechanics, not the board |
| H-7 switch wetting current | **Not changed on the board.** TI requires ≥ 350 kΩ from IN to EN/UVLO for reverse-polarity safety (TPS25947 abs-max note 2), so the contact carries about 6.6 µA. Requirement: use a sealed reed / magnetic switch or a switch rated for dry-circuit use (gold contacts) |
| H-8 TVS on pyro drains | Not adopted, with reason (`M3_ACTUATOR_MERGE.md` §2.2) |
| H-9 gate-source capacitor on the load switch | Done (C120 2.2 µF) |
| H-10 BAT54S pull-pin clamp | Done |

## 5. Firmware requirements the hardware relies on

R2 firmware does not exist yet. These are hardware-derived rules, in addition to `FMEA_REDUNDANCY.md` §5:
1. Every pyro fire pulse ends after **20 ms**. This is what protects R134/R135 when an igniter is shorted.
2. Flight state (phase and armed state) survives an MCU reset (FMEA V-2).
3. Channel 2 fires 2.0 s after channel 1 regardless of channel 1's continuity (single deploy, FMEA V-7).
4. Drive PE3 and PE6 low permanently (sentinels).
5. Read VLOGIC_SENSE and V3V3_SENSE on **ADC3** (PC2_C / PC3_C reach only ADC3 unless the analog switch is closed).
6. Evaluate the plug-out self-test ratiometrically (VREF+ = 3V3A). The thresholds come from `m3_design/sim_r2/RESULTS.md` §E.
7. Do not run v0.8.1 on R2.

## 6. How to re-check

```sh
bash tools/check.sh                    # DRC / unconnected / parity / ERC = 0, metadata / 3D audit
python3 m3_design/check_actuators.py   # safety contract from the PCB copper netlist
python3 m3_design/sim_r2/run.py        # SPICE suite (needs ngspice)
```

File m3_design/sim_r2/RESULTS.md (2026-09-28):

# M3-ASSY-R2 actuator band - SPICE results

Generated by `python3 m3_design/sim_r2/run.py` (ngspice-46 : Circuit level simulation program). Do not edit by hand; edit `run.py` and re-run.

These are **simulations of the schematic as drawn**, with datasheet-fitted level-1 models. They do not replace the
bench tests listed in `docs/M3_ACTUATOR_MERGE.md` section 4. See `FINDINGS.md` for the interpretation.

**Verdict counts:** DEMO 2, INFO 8, OLD-FAIL 6, PASS 135

`DEMO` rows are deliberate fault injections (a part removed) that show why the part is needed; they are expected to exceed the limit.
`OLD-FAIL` rows re-simulate R2 as merged in PR #1 (no R134/R135) for comparison; they are not the current design.

## Assumptions (off-board values)

| Item | Value |
|---|---|
| 2S LiPo EMF | 6.0 / 7.4 / 8.4 V |
| Pack internal resistance | 20 mOhm (fresh, hot) / 40 mOhm / 80 mOhm (cold, worn) |
| Battery lead | 100 nH + 20 mOhm wiring + 5 mOhm in-line 15 A ATO fuse (MARGIN_PRESCRIPTION P0-3b) |
| Logic load on BAT_IN through U9 | 28 ohm (~0.3 A at 8.4 V); U9 itself not modelled, RAW_PROTECTED = BAT_IN x enable |
| Fire pulse | 20 ms, ended by firmware (requirement from FINDINGS.md 1; firmware for R2 not written yet) |
| R134/R135 | Bourns CRM2512-FX-2R00ELF 2 ohm; single-pulse limit from the datasheet chart: 220 W @ 1 ms, 90 W @ 10 ms, 27 W @ 100 ms |
| Arming-plug fuse | Littelfuse 217 series 5 A fast-acting 5x20 (0217005): cold R 13.7 mOhm, nominal melting I2t 42.8 A2s (datasheet table); modelled as opening when the integrated I2t reaches 42.8 A2s (arc time ignored) |
| Logic brown-out | the R1 hold-up study (docs/SIMULATION.md) gives only ~3 ms of VLOGIC hold-up at 6.0 V / 0.5 A; any BAT_IN collapse longer than that resets the MCU |
| Igniter | MJG bridgewire 1.2 ohm + 1 m 26 AWG (134 mOhm) + 1 uH lead (MARGIN_PRESCRIPTION fire row) |
| Servo MKS HV6120 stalled | 4.385 ohm each, 1.096 ohm for all four (GEOMETRY_REV_G); cruise 1.5 A total |
| Plug insertion | 10 ns contact edge, two bounces (on 10 us, off 12 us, on 14 us, off 15 us, on 17 us) |
| ADC total error used for state separation | +/-20 mV (budget, not a datasheet figure) |

## A. Actuator switch (sheet 11)

| Item | Result | Limit | Verdict |
|---|---|---|---|
| turn-on 6.0 V, no load, typ FET: RAW_ACT 95 % | 9.0 ms after enable | < 100 ms (bring-up) | **PASS** |
| turn-on 6.0 V, no load, typ FET: Q121 pulse | E 7.7 mJ, Ppk 10.6 W, peak dTj 2.9 K | Tj 150 C from 60 C ambient -> dTj < 90 K | **PASS** |
| turn-off 6.0 V, no load, typ FET: Q121 pulse | E 0 mJ, Ppk 0.0 W, peak dTj 0.0 K; RAW_ACT bleeds down slowly (no load) | dTj < 90 K | **PASS** |
| turn-on 6.0 V, no load, slow-corner FET: RAW_ACT 95 % | 12.4 ms after enable | < 100 ms (bring-up) | **PASS** |
| turn-on 6.0 V, no load, slow-corner FET: Q121 pulse | E 7.8 mJ, Ppk 9.7 W, peak dTj 2.7 K | Tj 150 C from 60 C ambient -> dTj < 90 K | **PASS** |
| turn-off 6.0 V, no load, slow-corner FET: Q121 pulse | E 0 mJ, Ppk 0.0 W, peak dTj 0.0 K; RAW_ACT bleeds down slowly (no load) | dTj < 90 K | **PASS** |
| turn-on 6.0 V, cruise 1.5 A, typ FET: RAW_ACT 95 % | 9.1 ms after enable | < 100 ms (bring-up) | **PASS** |
| turn-on 6.0 V, cruise 1.5 A, typ FET: Q121 pulse | E 11.0 mJ, Ppk 11.2 W, peak dTj 3.3 K | Tj 150 C from 60 C ambient -> dTj < 90 K | **PASS** |
| turn-off 6.0 V, cruise 1.5 A, typ FET: Q121 pulse | E 8 mJ, Ppk 0.8 W, peak dTj 0.7 K; RAW_ACT < 10 % after 253 ms | dTj < 90 K | **PASS** |
| turn-on 6.0 V, cruise 1.5 A, slow-corner FET: RAW_ACT 95 % | 12.5 ms after enable | < 100 ms (bring-up) | **PASS** |
| turn-on 6.0 V, cruise 1.5 A, slow-corner FET: Q121 pulse | E 11.8 mJ, Ppk 10.3 W, peak dTj 3.2 K | Tj 150 C from 60 C ambient -> dTj < 90 K | **PASS** |
| turn-off 6.0 V, cruise 1.5 A, slow-corner FET: Q121 pulse | E 6 mJ, Ppk 0.7 W, peak dTj 0.6 K; RAW_ACT < 10 % after 197 ms | dTj < 90 K | **PASS** |
| turn-on 6.0 V, 4 servos stalled, typ FET: RAW_ACT 95 % | 9.3 ms after enable | < 100 ms (bring-up) | **PASS** |
| turn-on 6.0 V, 4 servos stalled, typ FET: Q121 pulse | E 70.6 mJ, Ppk 13.8 W, peak dTj 5.1 K | Tj 150 C from 60 C ambient -> dTj < 90 K | **PASS** |
| turn-off 6.0 V, 4 servos stalled, typ FET: Q121 pulse | E 135 mJ, Ppk 6.9 W, peak dTj 7.4 K; RAW_ACT < 10 % after 229 ms | dTj < 90 K | **PASS** |
| turn-on 6.0 V, 4 servos stalled, slow-corner FET: RAW_ACT 95 % | 12.8 ms after enable | < 100 ms (bring-up) | **PASS** |
| turn-on 6.0 V, 4 servos stalled, slow-corner FET: Q121 pulse | E 84.0 mJ, Ppk 13.0 W, peak dTj 5.3 K | Tj 150 C from 60 C ambient -> dTj < 90 K | **PASS** |
| turn-off 6.0 V, 4 servos stalled, slow-corner FET: Q121 pulse | E 107 mJ, Ppk 6.8 W, peak dTj 6.8 K; RAW_ACT < 10 % after 173 ms | dTj < 90 K | **PASS** |
| turn-on 8.4 V, no load, typ FET: RAW_ACT 95 % | 5.8 ms after enable | < 100 ms (bring-up) | **PASS** |
| turn-on 8.4 V, no load, typ FET: Q121 pulse | E 16.0 mJ, Ppk 27.0 W, peak dTj 6.8 K | Tj 150 C from 60 C ambient -> dTj < 90 K | **PASS** |
| turn-off 8.4 V, no load, typ FET: Q121 pulse | E 0 mJ, Ppk 0.0 W, peak dTj 0.0 K; RAW_ACT bleeds down slowly (no load) | dTj < 90 K | **PASS** |
| turn-on 8.4 V, no load, slow-corner FET: RAW_ACT 95 % | 7.8 ms after enable | < 100 ms (bring-up) | **PASS** |
| turn-on 8.4 V, no load, slow-corner FET: Q121 pulse | E 16.1 mJ, Ppk 25.5 W, peak dTj 6.3 K | Tj 150 C from 60 C ambient -> dTj < 90 K | **PASS** |
| turn-off 8.4 V, no load, slow-corner FET: Q121 pulse | E 0 mJ, Ppk 0.0 W, peak dTj 0.0 K; RAW_ACT bleeds down slowly (no load) | dTj < 90 K | **PASS** |
| turn-on 8.4 V, cruise 1.5 A, typ FET: RAW_ACT 95 % | 5.8 ms after enable | < 100 ms (bring-up) | **PASS** |
| turn-on 8.4 V, cruise 1.5 A, typ FET: Q121 pulse | E 21.6 mJ, Ppk 28.2 W, peak dTj 7.5 K | Tj 150 C from 60 C ambient -> dTj < 90 K | **PASS** |
| turn-off 8.4 V, cruise 1.5 A, typ FET: Q121 pulse | E 20 mJ, Ppk 1.8 W, peak dTj 1.7 K; RAW_ACT < 10 % after 330 ms | dTj < 90 K | **PASS** |
| turn-on 8.4 V, cruise 1.5 A, slow-corner FET: RAW_ACT 95 % | 7.8 ms after enable | < 100 ms (bring-up) | **PASS** |
| turn-on 8.4 V, cruise 1.5 A, slow-corner FET: Q121 pulse | E 22.6 mJ, Ppk 26.8 W, peak dTj 7.0 K | Tj 150 C from 60 C ambient -> dTj < 90 K | **PASS** |
| turn-off 8.4 V, cruise 1.5 A, slow-corner FET: Q121 pulse | E 15 mJ, Ppk 1.6 W, peak dTj 1.4 K; RAW_ACT < 10 % after 274 ms | dTj < 90 K | **PASS** |
| turn-on 8.4 V, 4 servos stalled, typ FET: RAW_ACT 95 % | 6.0 ms after enable | < 100 ms (bring-up) | **PASS** |
| turn-on 8.4 V, 4 servos stalled, typ FET: Q121 pulse | E 127.5 mJ, Ppk 34.3 W, peak dTj 10.1 K | Tj 150 C from 60 C ambient -> dTj < 90 K | **PASS** |
| turn-off 8.4 V, 4 servos stalled, typ FET: Q121 pulse | E 334 mJ, Ppk 14.4 W, peak dTj 16.0 K; RAW_ACT < 10 % after 314 ms | dTj < 90 K | **PASS** |
| turn-on 8.4 V, 4 servos stalled, slow-corner FET: RAW_ACT 95 % | 8.0 ms after enable | < 100 ms (bring-up) | **PASS** |
| turn-on 8.4 V, 4 servos stalled, slow-corner FET: Q121 pulse | E 149.2 mJ, Ppk 32.9 W, peak dTj 10.5 K | Tj 150 C from 60 C ambient -> dTj < 90 K | **PASS** |
| turn-off 8.4 V, 4 servos stalled, slow-corner FET: Q121 pulse | E 270 mJ, Ppk 14.2 W, peak dTj 15.0 K; RAW_ACT < 10 % after 259 ms | dTj < 90 K | **PASS** |

## B. Pyro channel fire (sheet 12)

| Item | Result | Limit | Verdict |
|---|---|---|---|
| 6.0 V, max-RDS FET, weakest-legal GPIO: gate reaches 2.5 V | 99 us | < 1 ms | **PASS** |
| 6.0 V, max-RDS FET, weakest-legal GPIO: final VGS | 3.07 V | >= 2.5 V (RDS(on) spec point) and <= 12 V | **PASS** |
| 6.0 V, max-RDS FET, weakest-legal GPIO: bridgewire current | 1.72 A steady | >= 1.0 A recommended all-fire (MJG), 0.6 A minimum | **PASS** |
| 6.0 V, max-RDS FET, weakest-legal GPIO: GPIO peak source current | 14.0 mA | <= 20 mA (DS12110 IIO) | **PASS** |
| 6.0 V, max-RDS FET, weakest-legal GPIO: FET dissipation while firing | 0.01 W | < PDSM 3.1 W | **PASS** |
| 6.0 V, max-RDS FET, weakest-legal GPIO: R134 during a 20 ms fire | 5.9 W | <= CRM2512 curve / 1.5 (42 W) | **PASS** |
| 6.0 V, max-RDS FET, strong GPIO: gate reaches 2.5 V | 78 us | < 1 ms | **PASS** |
| 6.0 V, max-RDS FET, strong GPIO: final VGS | 3.19 V | >= 2.5 V (RDS(on) spec point) and <= 12 V | **PASS** |
| 6.0 V, max-RDS FET, strong GPIO: bridgewire current | 1.72 A steady | >= 1.0 A recommended all-fire (MJG), 0.6 A minimum | **PASS** |
| 6.0 V, max-RDS FET, strong GPIO: GPIO peak source current | 17.2 mA | <= 20 mA (DS12110 IIO) | **PASS** |
| 6.0 V, max-RDS FET, strong GPIO: FET dissipation while firing | 0.01 W | < PDSM 3.1 W | **PASS** |
| 6.0 V, max-RDS FET, strong GPIO: R134 during a 20 ms fire | 5.9 W | <= CRM2512 curve / 1.5 (42 W) | **PASS** |
| 8.4 V, typ FET, weakest-legal GPIO: gate reaches 2.5 V | 99 us | < 1 ms | **PASS** |
| 8.4 V, typ FET, weakest-legal GPIO: final VGS | 3.07 V | >= 2.5 V (RDS(on) spec point) and <= 12 V | **PASS** |
| 8.4 V, typ FET, weakest-legal GPIO: bridgewire current | 2.46 A steady | >= 1.0 A recommended all-fire (MJG), 0.6 A minimum | **PASS** |
| 8.4 V, typ FET, weakest-legal GPIO: GPIO peak source current | 14.0 mA | <= 20 mA (DS12110 IIO) | **PASS** |
| 8.4 V, typ FET, weakest-legal GPIO: FET dissipation while firing | 0.02 W | < PDSM 3.1 W | **PASS** |
| 8.4 V, typ FET, weakest-legal GPIO: R134 during a 20 ms fire | 12.1 W | <= CRM2512 curve / 1.5 (42 W) | **PASS** |
| 8.4 V, typ FET, strong GPIO: gate reaches 2.5 V | 78 us | < 1 ms | **PASS** |
| 8.4 V, typ FET, strong GPIO: final VGS | 3.19 V | >= 2.5 V (RDS(on) spec point) and <= 12 V | **PASS** |
| 8.4 V, typ FET, strong GPIO: bridgewire current | 2.46 A steady | >= 1.0 A recommended all-fire (MJG), 0.6 A minimum | **PASS** |
| 8.4 V, typ FET, strong GPIO: GPIO peak source current | 17.2 mA | <= 20 mA (DS12110 IIO) | **PASS** |
| 8.4 V, typ FET, strong GPIO: FET dissipation while firing | 0.02 W | < PDSM 3.1 W | **PASS** |
| 8.4 V, typ FET, strong GPIO: R134 during a 20 ms fire | 12.1 W | <= CRM2512 curve / 1.5 (42 W) | **PASS** |

## B2. Pyro fire while all four servos are stalled (FMEA V-15)

| Item | Result | Limit | Verdict |
|---|---|---|---|
| 6.0 V pack 80 mOhm, max-RDS FET: bridgewire current | 1.57 A (RAW_ACT 5.27 V) | >= 1.0 A recommended all-fire (MJG) | **PASS** |
| 6.0 V pack 80 mOhm: BAT_IN during fire + stall | min 5.31 V | >= 5.0 V (logic stays up) | **PASS** |
| 7.4 V pack 40 mOhm, max-RDS FET: bridgewire current | 2.03 A (RAW_ACT 6.80 V) | >= 1.0 A recommended all-fire (MJG) | **PASS** |
| 7.4 V pack 40 mOhm: BAT_IN during fire + stall | min 6.85 V | >= 5.0 V (logic stays up) | **PASS** |

## C. Shorted igniter on channel 1 (fired into a short), fuse melting at its I2t, 20 ms fire pulse

| Item | Result | Limit | Verdict |
|---|---|---|---|
| short at J121 terminal, 8.4 V pack 20 mOhm, as drawn (R134 2 ohm): peak current / fuse | 4.1 A; fuse does not open | < IDM 112 A | **PASS** |
| short at J121 terminal, 8.4 V pack 20 mOhm, as drawn (R134 2 ohm): AON7524 junction | peak dTj 0 K | dTj < 90 K (Tj 150 C from 60 C) | **PASS** |
| short at J121 terminal, 8.4 V pack 20 mOhm, as drawn (R134 2 ohm): BAT_IN | min 8.21 V, below 5.0 V for 0.0 ms | below 5.0 V for < 3 ms (R1 hold-up study, 6.0 V corner) so the MCU does not reset and channel 2 still fires | **PASS** |
| short at J121 terminal, 8.4 V pack 20 mOhm, as drawn (R134 2 ohm): R134 pulse | 33.2 W for 20 ms; CRM2512 allows 63 W at that length | peak power <= CRM2512 single-pulse curve / 1.5 | **PASS** |
| short at J121 terminal, 8.4 V pack 20 mOhm, R2 as merged in #1 (no R134): peak current / fuse | 131.2 A; fuse opens at 4.0 ms | < IDM 112 A | **OLD-FAIL** |
| short at J121 terminal, 8.4 V pack 20 mOhm, R2 as merged in #1 (no R134): AON7524 junction | peak dTj 124 K | dTj < 90 K (Tj 150 C from 60 C) | **OLD-FAIL** |
| short at J121 terminal, 8.4 V pack 20 mOhm, R2 as merged in #1 (no R134): BAT_IN | min 3.68 V, below 5.0 V for 3.9 ms | below 5.0 V for < 3 ms (R1 hold-up study, 6.0 V corner) so the MCU does not reset and channel 2 still fires | **OLD-FAIL** |
| short at J121 terminal, 7.4 V pack 40 mOhm, as drawn (R134 2 ohm): peak current / fuse | 3.6 A; fuse does not open | < IDM 112 A | **PASS** |
| short at J121 terminal, 7.4 V pack 40 mOhm, as drawn (R134 2 ohm): AON7524 junction | peak dTj 0 K | dTj < 90 K (Tj 150 C from 60 C) | **PASS** |
| short at J121 terminal, 7.4 V pack 40 mOhm, as drawn (R134 2 ohm): BAT_IN | min 7.15 V, below 5.0 V for 0.0 ms | below 5.0 V for < 3 ms (R1 hold-up study, 6.0 V corner) so the MCU does not reset and channel 2 still fires | **PASS** |
| short at J121 terminal, 7.4 V pack 40 mOhm, as drawn (R134 2 ohm): R134 pulse | 25.8 W for 20 ms; CRM2512 allows 63 W at that length | peak power <= CRM2512 single-pulse curve / 1.5 | **PASS** |
| short at J121 terminal, 7.4 V pack 40 mOhm, R2 as merged in #1 (no R134): peak current / fuse | 109.6 A; fuse opens at 8.0 ms | < IDM 112 A | **PASS** |
| short at J121 terminal, 7.4 V pack 40 mOhm, R2 as merged in #1 (no R134): AON7524 junction | peak dTj 75 K | dTj < 90 K (Tj 150 C from 60 C) | **PASS** |
| short at J121 terminal, 7.4 V pack 40 mOhm, R2 as merged in #1 (no R134): BAT_IN | min 2.61 V, below 5.0 V for 7.9 ms | below 5.0 V for < 3 ms (R1 hold-up study, 6.0 V corner) so the MCU does not reset and channel 2 still fires | **OLD-FAIL** |
| short at J121 terminal, 6.0 V pack 80 mOhm, as drawn (R134 2 ohm): peak current / fuse | 2.9 A; fuse does not open | < IDM 112 A | **PASS** |
| short at J121 terminal, 6.0 V pack 80 mOhm, as drawn (R134 2 ohm): AON7524 junction | peak dTj 0 K | dTj < 90 K (Tj 150 C from 60 C) | **PASS** |
| short at J121 terminal, 6.0 V pack 80 mOhm, as drawn (R134 2 ohm): BAT_IN | min 5.69 V, below 5.0 V for 0.0 ms | below 5.0 V for < 3 ms (R1 hold-up study, 6.0 V corner) so the MCU does not reset and channel 2 still fires | **PASS** |
| short at J121 terminal, 6.0 V pack 80 mOhm, as drawn (R134 2 ohm): R134 pulse | 16.7 W for 20 ms; CRM2512 allows 63 W at that length | peak power <= CRM2512 single-pulse curve / 1.5 | **PASS** |
| short at J121 terminal, 6.0 V pack 80 mOhm, R2 as merged in #1 (no R134): peak current / fuse | 84.9 A; fuse does not open | < IDM 112 A | **PASS** |
| short at J121 terminal, 6.0 V pack 80 mOhm, R2 as merged in #1 (no R134): AON7524 junction | peak dTj 28 K | dTj < 90 K (Tj 150 C from 60 C) | **PASS** |
| short at J121 terminal, 6.0 V pack 80 mOhm, R2 as merged in #1 (no R134): BAT_IN | min 1.53 V, below 5.0 V for 20.1 ms | below 5.0 V for < 3 ms (R1 hold-up study, 6.0 V corner) so the MCU does not reset and channel 2 still fires | **OLD-FAIL** |
| short at the igniter end of 1 m lead, 8.4 V pack 20 mOhm, as drawn (R134 2 ohm): peak current / fuse | 3.8 A; fuse does not open | < IDM 112 A | **PASS** |
| short at the igniter end of 1 m lead, 8.4 V pack 20 mOhm, as drawn (R134 2 ohm): AON7524 junction | peak dTj 0 K | dTj < 90 K (Tj 150 C from 60 C) | **PASS** |
| short at the igniter end of 1 m lead, 8.4 V pack 20 mOhm, as drawn (R134 2 ohm): BAT_IN | min 8.22 V, below 5.0 V for 0.0 ms | below 5.0 V for < 3 ms (R1 hold-up study, 6.0 V corner) so the MCU does not reset and channel 2 still fires | **PASS** |
| short at the igniter end of 1 m lead, 8.4 V pack 20 mOhm, as drawn (R134 2 ohm): R134 pulse | 29.3 W for 20 ms; CRM2512 allows 63 W at that length | peak power <= CRM2512 single-pulse curve / 1.5 | **PASS** |
| short at the igniter end of 1 m lead, 8.4 V pack 20 mOhm, R2 as merged in #1 (no R134): peak current / fuse | 43.3 A; fuse does not open | < IDM 112 A | **PASS** |
| short at the igniter end of 1 m lead, 8.4 V pack 20 mOhm, R2 as merged in #1 (no R134): AON7524 junction | peak dTj 30 K | dTj < 90 K (Tj 150 C from 60 C) | **PASS** |
| short at the igniter end of 1 m lead, 8.4 V pack 20 mOhm, R2 as merged in #1 (no R134): BAT_IN | min 6.58 V, below 5.0 V for 0.0 ms | below 5.0 V for < 3 ms (R1 hold-up study, 6.0 V corner) so the MCU does not reset and channel 2 still fires | **PASS** |
| short at the igniter end of 1 m lead, 7.4 V pack 40 mOhm, as drawn (R134 2 ohm): peak current / fuse | 3.4 A; fuse does not open | < IDM 112 A | **PASS** |
| short at the igniter end of 1 m lead, 7.4 V pack 40 mOhm, as drawn (R134 2 ohm): AON7524 junction | peak dTj 0 K | dTj < 90 K (Tj 150 C from 60 C) | **PASS** |
| short at the igniter end of 1 m lead, 7.4 V pack 40 mOhm, as drawn (R134 2 ohm): BAT_IN | min 7.17 V, below 5.0 V for 0.0 ms | below 5.0 V for < 3 ms (R1 hold-up study, 6.0 V corner) so the MCU does not reset and channel 2 still fires | **PASS** |
| short at the igniter end of 1 m lead, 7.4 V pack 40 mOhm, as drawn (R134 2 ohm): R134 pulse | 22.6 W for 20 ms; CRM2512 allows 63 W at that length | peak power <= CRM2512 single-pulse curve / 1.5 | **PASS** |
| short at the igniter end of 1 m lead, 7.4 V pack 40 mOhm, R2 as merged in #1 (no R134): peak current / fuse | 37.3 A; fuse does not open | < IDM 112 A | **PASS** |
| short at the igniter end of 1 m lead, 7.4 V pack 40 mOhm, R2 as merged in #1 (no R134): AON7524 junction | peak dTj 19 K | dTj < 90 K (Tj 150 C from 60 C) | **PASS** |
| short at the igniter end of 1 m lead, 7.4 V pack 40 mOhm, R2 as merged in #1 (no R134): BAT_IN | min 5.29 V, below 5.0 V for 0.0 ms | below 5.0 V for < 3 ms (R1 hold-up study, 6.0 V corner) so the MCU does not reset and channel 2 still fires | **PASS** |
| short at the igniter end of 1 m lead, 6.0 V pack 80 mOhm, as drawn (R134 2 ohm): peak current / fuse | 2.7 A; fuse does not open | < IDM 112 A | **PASS** |
| short at the igniter end of 1 m lead, 6.0 V pack 80 mOhm, as drawn (R134 2 ohm): AON7524 junction | peak dTj 0 K | dTj < 90 K (Tj 150 C from 60 C) | **PASS** |
| short at the igniter end of 1 m lead, 6.0 V pack 80 mOhm, as drawn (R134 2 ohm): BAT_IN | min 5.70 V, below 5.0 V for 0.0 ms | below 5.0 V for < 3 ms (R1 hold-up study, 6.0 V corner) so the MCU does not reset and channel 2 still fires | **PASS** |
| short at the igniter end of 1 m lead, 6.0 V pack 80 mOhm, as drawn (R134 2 ohm): R134 pulse | 14.8 W for 20 ms; CRM2512 allows 63 W at that length | peak power <= CRM2512 single-pulse curve / 1.5 | **PASS** |
| short at the igniter end of 1 m lead, 6.0 V pack 80 mOhm, R2 as merged in #1 (no R134): peak current / fuse | 29.6 A; fuse does not open | < IDM 112 A | **PASS** |
| short at the igniter end of 1 m lead, 6.0 V pack 80 mOhm, R2 as merged in #1 (no R134): AON7524 junction | peak dTj 9 K | dTj < 90 K (Tj 150 C from 60 C) | **PASS** |
| short at the igniter end of 1 m lead, 6.0 V pack 80 mOhm, R2 as merged in #1 (no R134): BAT_IN | min 3.66 V, below 5.0 V for 20.0 ms | below 5.0 V for < 3 ms (R1 hold-up study, 6.0 V corner) so the MCU does not reset and channel 2 still fires | **OLD-FAIL** |
| R134 if the gate is left on (firmware fault), 8.4 V dead short | 35 W reaches the CRM2512 curve after ~60 ms | info: the resistor then fails open (channel lost, no fuse action); firmware must end every fire pulse | **INFO** |

## D. ARM plug insertion, FET off (Miller self-turn-on)

| Item | Result | Limit | Verdict |
|---|---|---|---|
| C126 fitted, MCU unpowered/reset: peak VGS | 17 mV | < VGS(th) min 0.4 V | **PASS** |
| C126 fitted, MCU unpowered/reset: igniter transient | peak 1.23 A, I2t 0.81 uA2s; FET peak 0.029 A | no-fire 0.30 A continuous (MJG); I2t << 1 mA2s | **PASS** |
| C126 fitted, MCU driving low: peak VGS | 17 mV | < VGS(th) min 0.4 V | **PASS** |
| C126 fitted, MCU driving low: igniter transient | peak 1.23 A, I2t 0.81 uA2s; FET peak 0.029 A | no-fire 0.30 A continuous (MJG); I2t << 1 mA2s | **PASS** |
| C126 MISSING (fault), MCU unpowered/reset: peak VGS | 499 mV | < VGS(th) min 0.4 V | **DEMO** |
| C126 MISSING (fault), MCU unpowered/reset: igniter transient | peak 1.24 A, I2t 2.48 uA2s; FET peak 1.137 A | no-fire 0.30 A continuous (MJG); I2t << 1 mA2s | **PASS** |
| C126 MISSING (fault), MCU driving low: peak VGS | 479 mV | < VGS(th) min 0.4 V | **DEMO** |
| C126 MISSING (fault), MCU driving low: igniter transient | peak 1.23 A, I2t 1.16 uA2s; FET peak 0.771 A | no-fire 0.30 A continuous (MJG); I2t << 1 mA2s | **PASS** |

## E. Continuity / arm-sense states (split buses, cold pull-up)

| Item | Result | Limit | Verdict |
|---|---|---|---|
| plug out, igniter OK, FET OK | CONT 95.1..99.8 mV, ARM 95.1..99.8 mV (ADC reading, ratiometric to 3V3A) |  | **INFO** |
| plug out, igniter OPEN, FET OK | CONT 140.8..147.7 mV, ARM 0.0..0.0 mV (ADC reading, ratiometric to 3V3A) |  | **INFO** |
| plug out, igniter OK, FET SHORTED | CONT 0.0..0.0 mV, ARM 0.0..0.0 mV (ADC reading, ratiometric to 3V3A) |  | **INFO** |
| plug out, igniter OPEN, FET SHORTED | CONT 0.0..0.0 mV, ARM 0.0..0.0 mV (ADC reading, ratiometric to 3V3A) |  | **INFO** |
| plug in, igniter OK, FET OK | CONT 507.7..817.7 mV, ARM 507.9..818.0 mV (ADC reading, ratiometric to 3V3A) |  | **INFO** |
| plug in, igniter OPEN, FET OK | CONT 140.8..147.7 mV, ARM 507.9..818.0 mV (ADC reading, ratiometric to 3V3A) |  | **INFO** |
| separation: detect a shorted FET before the plug goes in (FMEA H-1) | 95.1 mV gap between worst-case ranges | > 2 x 20 mV ADC error | **PASS** |
| separation: igniter continuity with the plug out | 41.0 mV gap between worst-case ranges | > 2 x 20 mV ADC error | **PASS** |
| separation: bus armed vs not armed | 408.1 mV gap between worst-case ranges | > 2 x 20 mV ADC error | **PASS** |
| separation: igniter continuity with the plug in | 360.0 mV gap between worst-case ranges | > 2 x 20 mV ADC error | **PASS** |
| ADC node voltage at RAW_ACT = 8.4 V | ARM/CONT 0.76 V, RAW_ACT_SENSE 2.69 V | analog-mode pin <= VDDA 3.3 V | **PASS** |
| ADC node voltage at RAW_ACT = 15.4 V | ARM/CONT 1.40 V, RAW_ACT_SENSE 4.92 V (TVS-clamp transient only; < 0.2 mA through R124) | analog-mode pin <= VDDA 3.3 V | **INFO** |
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

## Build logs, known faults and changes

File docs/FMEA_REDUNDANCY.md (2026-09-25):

# Rocket Flight Computer v1 — Redundancy Architecture and Fault-Tolerance Ruling (REDUNDANCY-1, 2026-09-03)

> This document revises all of the firmware constraints in `ROCKET_FC_FROZEN_DESIGN.md` §7, and proposes schematic changes to §2.3 / §3.9 / §5.2 that must be implemented before fab. Geometry follows `GEOMETRY_REV_G.md`.
> **Severity order (the document's only weighting)**: ① inadvertent firing on the ground / during handling (personal injury) > ② no deployment (ballistic, total loss, range incident) > ③ deployment at the wrong time (high-speed deployment, shredded recovery) > ④ loss of roll control (mission failure, rocket usually recoverable) > ⑤ loss of log/telemetry.
> **First principle throughout**: any change that trades a ⑤ or ④ risk for a ② or ① risk is rejected, however "safe" it looks.

---

## 1. Single-point-of-failure list

Criterion: a **single** component, solder joint, wire, register write or human action is enough to cause the consequence. Sorted by severity.

### 1.1 INJURY class (inadvertent firing on the ground / during handling)

| # | Failure | Cause | Detectable today? | Consequence | Backstop |
|---|---|---|---|---|---|
| **I-1** | **Q3/Q4 (AO3400A) drain-source short** | Accumulated damage from the previous flight's 4.0–9.84 A pulses (rev G §5.6 rates 9.84 A MARGINAL); ESD; a solder bridge between the adjacent SOT-23 drain and source | **No — and the "FET short self-test" claimed in §7 cannot be implemented on this netlist.** `PYRO1_OUT = {J4.4, Q3.3, R18.1}`; the only path up from the drain is igniter → `PYRO_BUS`, and with the ARM plug out `PYRO_BUS` is pulled to 0 V through R14/R15. Plug out: a healthy FET, a shorted FET, an open igniter and no igniter **all read 0 V** on PC0. Plug in: a shorted FET has already fired the charge | The charge fires the moment the operator is holding the ARM plug | **None.** Change H-1 (cold drain pull-up + BAT54A blocking) turns it into a cold measurement **before** the plug goes in; procedure P-2 (power up and self-test first, connect ARM after) downgrades the whole class of "only shows up at power-up" faults to bench findings |
| **I-2** | **An adjacent-pin solder bridge onto a pyro gate** | LQFP100, 0.5 mm pitch. `PE3 = LED_RED (pin 2) / PE4 = PYRO1_GATE (pin 3) / PE5 = PYRO2_GATE (pin 4) / PE6 = BUZZ_GATE (pin 5)` are four consecutive pins. The gate network 470R + 1k + 10 nF (τ = 4.7 µs) passes both the red LED's hundreds-of-ms highs and the 2.7 kHz buzzer drive; 3.3 V through the 470R/1k divider gives 2.24 V at the gate, **far above the AO3400A's true maximum threshold of 1.45 V** (rev G §5.7) | **No.** With ARM out the drain is always 0 V, so no test can see gate activity | The charge fires on the bench | **None.** Change H-2 (separate the two gates and surround them with sentinel pins driven low) + H-1 make the bridge testable (toggle the red LED / buzzer and watch whether CONT collapses) |
| **I-3** | **A single solder bridge between PE4 ↔ PE5** | Same as above; the two are physically adjacent | No (as I-1). Testable after H-1: driving gate 1 must not move drain 2 | One fire command fires both channels. The main comes out with the drogue at apogee (③); two charges in one compartment may over-pressure and break the airframe; ~13.6 A from both channels through the single 5 A fuse | None. Removed structurally by H-2 |
| **I-4** | **A stray strand on the J-ARM terminal bridging RAW to PYRO_BUS** | In the netlist `J4.1 = RAW` and `J4.2 = PYRO_BUS` are **adjacent**; after rev G §3.3's reorder `ARM_A (RAW)` and `ARM_B (PYRO_BUS)` are still adjacent. Stranded wire splaying in a 5.08 mm screw terminal is a standard failure | **The hardware already has the sensor; firmware never looks in this direction.** §7.4 uses ARM_SENSE in one direction only, "confirm armed before firing". With a stray strand, `ARM_SENSE = 0.764 V` while the plug is visibly out | As long as the reed switch is closed, the vehicle is **permanently armed**, and the 5 A fuse is bypassed. Every safety inference the operator draws from "the plug is out" is void | Firmware rule F-14 (negative ARM_SENSE check) + procedure P-1 (termination outside the airframe, only tinned solid wire or ferrules, every wire re-checked with a DMM) |
| **I-5** | **AP63203 high-side FET short → VLOGIC (≈ 8 V) straight onto 3V3** | Single-point failure of a synchronous buck | **No**, the MCU is itself the victim | PE4 at 8 V through the 470R/1k gives 5.4 V, far above threshold → fire. The MCU dies at the same time; no firmware defence exists | Cannot be covered in firmware. The only effective measure is **the order in procedure P-2**: power up → self-test → tone → **only then** connect the ARM link. Optional H-9 (3.6 V clamp on 3V3, which fails short = board dies on the bench) |
| **I-6** | **Q2 (AON6403) drain-source short, or the SW wire chafing to ground** | The main MOSFET failure mode is a drain-source short; `GATE_SW = {Q1.4, Q2.4, R1.1, R2.1}` leaves the board through R2 (10k) to `SW_TERM = {J1.3, J1.4}` on an **unclamped bare wire** (frozen §8 item 6 gave that treatment only to the pull-pin, not to the SW pair with far more serious electrical consequences) | **Nothing in the netlist reads back switch state.** The only available check is bench test T-1: battery connected, external switch OFF, USB plugged in — `VBAT_SENSE (PC4)` must then read **< 0.2 V** (RAW floats only through R3's 147k). Anything higher means a shorted FET or stuck switch | The board cannot be turned off → inserting the ARM plug energises a live bus | Bench test T-1 (zero cost, uses the existing divider) + procedure: SW twisted pair, opposite side from the pyro/servo harness, separate ties |
| **I-7** | **No "lift-off latch" as a precondition for firing** | §7.4 only requires reading ARM_SENSE and CONT and **never requires any flight-phase condition**. A design gap, not a component failure | **Undetectable** (a design property, not a runtime event). The board's IMU and barometer show it can be implemented, not that its absence can be noticed | While armed, **any single** firmware defect, stack overflow or EMI glitch driving a gate high releases energy | Firmware rule F-6 (LIFTOFF latch, two-source OR, never cleared for the whole flight). This is also the safety precondition for any "re-arm after reset" scheme |
| **I-8** | **No disarm after landing** | §7 defines launch detection and apogee detection but **never defines LANDED**. After landing the reed switch is still closed, the ARM plug still in, and 0.764 mA still flows through the unfired channel's bridgewire | Yes (stable pressure + \|a\| ≈ 1 g + a time floor), but the state does not exist today | Recovery crew walk up to a rocket still in flight state carrying an unfired charge. The most common real injury scenario in this field | Firmware rule F-8 (LANDED → permanent disarm, cleared only by power-off) + procedure P-5 (approach from the side, pull the ARM plug first, then switch off, then touch the airframe) |

### 1.2 VEHICLE_LOSS class

| # | Failure | Cause | Detectable today? | Consequence | Backstop |
|---|---|---|---|---|---|
| **V-1** | **IMU DRDY stops → IWDG never fed → reset → pyros permanently disarmed** | §3.4 pin 40 and §7.1: `the IWDG is fed only in this ISR`. The ICM-45686 is a 2.5 × 3.0 mm LGA-14 with no lead compliance; a cracked joint under 30 g boost vibration, SPI1 losing sync or latch-up — any of these stops the 800 Hz edges | **Today the only "detector" is the reset itself, which is the fault.** A DRDY edge counter checked by an independent timer would detect it within 25 ms | One sensor hiccup escalates a ④-class event into a ② total loss | The full ruling in §2. Core: **an IMU stall must only degrade, never reset** |
| **V-2** | **A reset loses the "flight phase", not just the arm bit** | The state machine restarts in PAD; launch detection is a boost-transient criterion that will never be true again at 2 km and 0 m/s | Completely undetectable today (no state persists across reset) | **Even with the pyros correctly re-armed, the rocket will not fire**, because it thinks it is on the pad. That is the real end of the kill chain | Firmware rule F-4 (.noinit flight record + flash phase log + live-evidence cross-check) |
| **V-3** | **The fire pulse is terminated by software** | §7.4 only says "pulse ≤ 20 ms" without specifying how. If the CPU hangs / HardFaults / is hit by EMI mid-pulse, the gate stays high | Visible in the log afterwards; undetectable in flight | Rev G §5.6: 6.81 A / 3.09 W into a 1.0 Ω load, RthJA 125 °C/W → **313 °C** steady-state rise, FET destroyed (and MOSFETs tend to fail **short** → next flight becomes I-1). The 5 A fuse at 136 % of rating "may take minutes to blow" and does not cover this intermediate state. An IWDG period of 2 s × 6.81 A = 93 A²s, enough to blow the shared fuse → the second channel dies too | Firmware rule F-9: hardware termination (the highest-priority timer ISR writes BSRR directly, or a timer compare event triggers a DMA write to `GPIOE->BSRR`) + rev G's independent TIM2 25 ms hard abort + IWDG period shortened to ~400 ms |
| **V-4** | **L2 (4.7 µH SWPA4030) open** | Netlist: `3V3A = {L2.2, U1.20 (VREF+), U1.21 (VDDA), U4.5/U4.8 (IMU), U5.1/U5.2 (MS5611), U6.2/U6.17 (GNSS), ...}`. **One 3 mm-tall wirewound inductor in single string ahead of every sensor and the ADC reference** | Free to test but not done today: solve VDDA from `VREFINT` against `VREFIN_CAL (0x1FF1E860)` (§7.9 already reads it, just not as a fault signal); add AVD @ 2.8 V | IMU + barometer + GNSS + **the whole ADC scale** die together. `PYRO*_CONT`, `ARM_SENSE` and `VBAT_SENSE` then read wrong but mutually consistent. **It punches through every "voting" and "cross-check" redundancy on the board at once** | Firmware rule F-12 (VREFINT criterion + "all three sensors lost at once" classified as one RAIL_DEAD code) + procedure (L2/L1 on the staking and pull-check list). **The strongest single argument for a permanently fitted backup altimeter** |
| **V-5** | **The single 5 A fuse + the single PYRO_BUS in series ahead of both channels** | `PYRO_BUS = {J4.2, J4.3, J4.5, R14.1}`, one net, three terminal positions. The ARM plug is its only bridge to RAW | Partly: after the fuse blows `ARM_SENSE → 0` while `VBAT_SENSE` is normal — a clear signature (F-13) | One igniter shorted (crushed, against the airframe wall) → 40 A-class short → fuse blows → **both channels dead**. "Two pyro channels" are therefore not redundant against anything upstream | Structural: H-5 (split PYRO_BUS into two independently fused buses, a netlist-only change). Otherwise only P-1's per-wire DMM check + a permanent backup altimeter. **A normal fire does not threaten the fuse**: 20 ms × 6.81 A = 0.93 A²s, while a blade fuse's melting I²t is tens of A²s → **do not shorten the pulse** (see the rejected items in §4) |
| **V-6** | **25 MHz HSE crystal failure with CSS not enabled** | Y1 is a mechanical resonator in a 30 g environment, next to the lever arm of a 14 mm screw terminal. A grep of all six documents finds no `CSS` and no `HSI` fallback | Yes (CSS raises an NMI), but not enabled | PLL loses lock → CPU stops → silent, complete, no deployment. **No watchdog strategy can save it** (the core has no clock). With a blocking wait for HSE-ready at boot, not even the IWDG is running yet | Firmware rule F-2 (CSSHSEON + NMI switches to HSI + **recompute every time constant**: 200 → 64 MHz stretches a 20 ms pulse to 62 ms, straight into V-3's thermal-destruction zone) |
| **V-7** | **§7.4 makes ARM_SENSE and PYRO*_CONT preconditions for firing** | Verbatim: "before firing, read ARM_SENSE to confirm armed and PYRO*_CONT to confirm the bridgewire is present". Implemented literally, that is a veto | N/A — a rule defect | One cracked 0402, one ADC channel stuck at zero, one VREF disturbance, and a healthy rocket refuses to deploy. The costs are wildly asymmetric: **firing into an open bridgewire costs nothing; refusing to fire into a good one costs the vehicle.** And both readings' reference sits behind V-4's L2 | Firmware rule F-10 (**in flight, sense readings are only logged and annunciated and never veto a fire**; on the ground they are hard refusals, because refusing on the ground is free) |
| **V-8** | **Blocked static port / failed bay seal / sunlight on the MS5611** | Assembly side: tape, filler, a misaligned sled, epoxy overflow; a translucent coupler | Partly: 30 s pressure σ (**log only, no alarm** — it misjudges on a calm day); dP/dT correlation (a sealed bay follows Gay-Lussac: `1013 / 293 = 3.457 hPa/K = 29 m/K`, so 5 K of sun is 145 m); a human-in-the-loop block/release test (the only reliable one on a calm day) | Late or missed apogee (②), or a completely wrong main altitude (③). **And the primary and backup altimeters share the same bay and the same vents → electronic redundancy is useless against it** | Procedure P-3 (3–4 small holes at 120°, away from the sensor, sealed bulkheads, a bench leak test, a ground ejection test) + firmware F-11 (keep an inertial vote in the apogee decision, so that §7.7's "the accelerometer must not be promoted" becomes a **conditional** rule) |
| **V-9** | **MS5611 stuck value / light sensitivity / ejection pressure shock** | A hung I2C (the spare header shares I2C1, admitted low-confidence in §3.6), the internal ADC stalling, ejection gas leaking into the av-bay. **Unique to this rocket**: the MS5611 is a gel-covered bare die and is light-sensitive, and this rocket **rolls actively** → a beam of sunlight through a vent sweeps the sensor at the roll frequency, producing a "live, plausible-looking" periodic pressure error | Yes, but only with the right criterion: **N consecutive identical raw D1 words**, never a threshold on the engineering value — pressure is naturally constant at apogee, so a threshold detector would **declare the barometer dead exactly when it is needed most** | Missed apogee (②), or frozen below main altitude → main at apogee (③) | Firmware rule F-11's full BARO_VALID set + 500 ms blinding after each fire + a vented foam cover over the sensor (blocks light and cushions ejection shock) + no line of sight from vent to sensor |
| **V-10** | **Battery / load switch / buck / 3V3 / MCU / firmware image — all single-string** | Architecture | A dead buck cannot test itself; the battery can be tested on the ground (load step T-2) | Total loss | **Cannot be covered on the board.** The only backstop is §3's permanently fitted independent commercial altimeter |
| **V-11** | **Reed/magnetic switch bouncing under vibration → whole-board power loss → POR** | Reed blades have mechanical resonances in the low kHz; `SW_TERM` carries only 76 µA, **below the wetting current of any non-hermetic contact**, and oxide films grow with life | Afterwards, yes (RCC_RSR POR/BOR + boot counter) | Power loss is worse than a reset: `.noinit` SRAM and the VBAT domain (VBAT copper-tied to VDD) **vanish together** | Existing immunity is ~1 ms (the gate charges through R1's 100k from −7.64 V to the worst-case −2.2 V threshold in about 0.95 ms) + 12.5–18 ms from the logic-side 470 µF. The residual risk is a **magnet-shift-class long open**, covered by F-4's reference-free live-evidence path. H-7 (R2 10k → 1k, raising the wetting current) needs zero new part numbers |
| **V-12** | **An open pull-pin reads as "pulled"** | `PULLPIN = {R36.1, R37.1, U1.61}`, R36 10k pull-up to 3V3, R37 1k in series to J6.1, J6.2 = GND. A broken wire = 3.30 V = "pulled", i.e. the permissive state | Yes (require firmware to **witness** a LOW → HIGH transition; high at power-up = fault) | If the pull-pin is given interlock authority: a broken wire silently removes the interlock (direction ①); a chafe to ground reads "inserted" in flight → **inhibits deployment** (direction ②). **No polarity is safe for both** | Firmware rule F-7: the pull-pin is **advisory only**, may only gate the ground PAD_ARMED → READY transition, and is **completely ignored** after launch detection; the witnessed transition is written to `.noinit` so a brown-out reset on the pad does not cause a refusal to arm |
| **V-13** | **QSPI /WP and /HOLD floating** | §1 deleted the two pull-ups on the grounds that "in 4-bit mode they are driven data lines". **But the part ships with QE = 0**: the JEDEC ID read, status-register reads and the write that sets QE are all single-line transfers during which QUADSPI does not drive IO2/IO3 | Indirectly (read-back verification fails), but §7's "all storage errors are non-fatal" guarantees it is silently swallowed | /HOLD floating low = the part freezes mid-transfer; /WP floating low + SRP = 1 = status register cannot be written. **And this is the very path that carries the self-test for "writes accepted but not stored"** | H-3: restore 2 × 10k (`C25744`, already used 13 times, zero new part numbers) |
| **V-14** | **A jumper or debris left between J2 pin 5 (3V3) and pin 6 (BOOT0)** | §1 explicitly replaced the BOOT0 button with "a jumper selects DFU" — i.e. **the normal maintenance action is shorting these two pins** | Completely undetectable (the ROM bootloader reports nothing, and the LEDs are invisible inside a closed rocket) | Every power-up enters the ROM bootloader and the flight software never runs. The gates are safe (PE4/PE5 are not in the AN2606 driven list), so this is a **silent ②**, not ① | Procedure P-2: the jumper is a bench tool and never flies; J2 wrapped in clear heat shrink before flight; **"a boot tone must be heard at power-up" is a hard go/no-go** — silence means abort (also covers V-14, I-1 and an unfinished erase) |
| **V-15** | **Roll-control integrator wind-up at zero dynamic pressure → all four servos hard-over, exactly at the fire instant** | §7 never says when roll control ends. In coast dynamic pressure goes to zero, the fins lose authority, and the integrator winds up to full deflection | Yes (rolling minimum of VBAT_SENSE + sign consistency between commanded and measured roll acceleration) | Rev G §5.5: four stalled servos at 7.66 A + a fire at 6.81–9.84 A = **14.5–17.5 A**, on the same RAW and the same 492 µF. With a 6.2 V battery RAW drops to 4.03 V and VLOGIC to 3.63 V < the AP63203's 3.8 V minimum input → brown-out reset, **exactly at the moment of firing**. Does not happen with a full 8.4 V battery | Firmware rule F-5: **end roll control at burnout** (the mission objective is over by then) + command all four to the 1520 µs centre 200 ms before firing, then stop PWM + anti-windup clamping |
| **V-16** | **A stray strand bridging PYRO_BUS to the same channel's OUT** | `J4.3 (PYRO_BUS)` is next to `J4.4 (PYRO1_OUT)`; in rev G's order `PYRO1_B` is next to `PYRO1_A` | **Not at all.** The drain is pulled to PYRO_BUS, so `PYRO*_CONT` reads exactly the healthy 0.764 V, and H-1's cold test reads healthy too | At fire time a bus-to-ground dead short → fuse blows → both channels dead, and the igniter never even heats | Only procedure P-1: with ARM out and both igniters fitted, measure `J4.4 ↔ J4.5` and `J4.6 ↔ J4.5` on a DMM low-current range; they must read the igniter resistance (≥ 1.0 Ω, a rev G hard requirement), and near zero means abort. Record the values on the flight card |
| **V-17** | **J-ARM pin definitions conflict between two documents, and nobody has ruled** | Netlist: `J4.1 = RAW / J4.2, 3, 5 = PYRO_BUS / J4.4 = PYRO1_OUT / J4.6 = PYRO2_OUT`. Rev G §3.3, aft → forward: `PYRO1_B / PYRO1_A / PYRO2_B / PYRO2_A / ARM_A / ARM_B`. **They differ** | N/A | This is the connector the operator terminates live-charge leads into by hand, outside the airframe, from a drawing — and rev G §7.3-3 says it is **unreachable once inside the airframe**. Miswired = ① or ② | Rule before fab and write down which wins; silkscreen must print **function names**, not numbers; the schematic notes have already shown this library's pin-numbering conventions cannot be extrapolated (two LEDs on the same board with opposite polarity numbering) |
| **V-18** | **The ARM plug is physically unreachable in flight configuration** | Rev G §7.3-3: the DB128V screw axis is ~5.25 mm inside the wire-entry face, J-ARM has 8.34 mm of clearance, an M2.5 screwdriver will not fit → "all 6 ARM/PYRO wires must be terminated outside the airframe … any re-termination on the pad requires pulling the sled"; §3.4: "no service port inside the airframe" | N/A | **The premise of the entire safety argument ("the ARM plug goes in last and comes out first") does not hold in flight configuration.** Either it becomes a flying plug dangling outside the airframe (new failures: yanked off by the harness at 30 g, chafing on the airframe wall), or it is already in when the airframe is closed and the reed switch becomes the only pad interlock — and the reed switch **has no state readback in the netlist** | Must be ruled before fab (see H-6 in §4). The second most important open item in this review |
| **V-19** | **No LANDED state → no location, no landing report, no disarm** | Undefined in §7 | N/A | A rocket that deploys normally and drifts 1–2 km downwind into crops is as completely lost as a ballistic one, and the log is lost with it (no telemetry on board; LoRa is unfitted pads only) | Firmware F-8 + procedure: **a permanently fitted independent commercial GPS tracker from the first flight** (own battery, own switch). The best value item on this list |
| **V-20** | **The buzzer is inaudible at any legal safe distance; and "silence" has five meanings** | MLT-8530 rated 80 dB @ 10 cm → **30.3 dB** free-field at 30.5 m, lower through the airframe, against a 45–55 dBA site background. `LS1.1 = 3V3`, so a flat battery, an open reed switch, a dead buck, a hung MCU, an open coil and firmware that didn't intend to beep are **acoustically identical** | N/A (a design property) | The operator walks away believing the rocket is armed when it is actually dead, or the reverse | Firmware F-15 (**silence is always a fault**; an unconditional "proof of life" chirp within 50 ms of reset) + procedure P-4 (**the last step is confirming the READY tone at ≤ 1 m; after walking away there is no further information**) + aim one vent at the buzzer as a sound port |

---

## 2. Ruling on the watchdog / reset chain

### 2.1 Diagnosis: the chain was misdiagnosed, and the reality is worse

The brief's chain was: `IMU stops → IWDG not fed → reset → permanently disarmed → no deployment`. Three corrections:

1. **"Permanently disarmed" misreads the frozen text.** §7.4 says `never automatically re-arm after a reset (requires an explicit ground command **or a definite flight-phase condition**)`. The second disjunct already authorises what we want to do — **the rule is not wrong, it is undefined**. So this section does not overturn §7.4; it pins down that "definite flight-phase condition".
2. **Even with the arm bit correctly restored, the rocket will not deploy.** The state machine also restarts in PAD, and launch detection is a boost-transient criterion that will never be true again at 2 km and 0 m/s. **What must survive a reset is the flight phase, the pad pressure reference, the launch time and each channel's fired flag — not just one arm bit.**
3. **The IMU is only one entry point, and a different feeding scheme does nothing for the others**: (a) resets from the fire event's own ground bounce and drain avalanche; (b) reed-switch bounce — a **power loss**, not a reset, which takes `.noinit` and the VBAT domain with it; (c) V-15's concurrent stall + fire droop; (d) HardFault; (e) **DRDY stuck or chattering** — under the current rule it would **keep feeding the dog** at kHz rates while starving the main loop, a completely silent failure with the watchdog pointed at exactly the wrong task.

### 2.2 Ruling

**Reject "add a second timer that feeds the dog"**: that only proves the NVIC is alive and does nothing for anything downstream of a reset.

**Adopt a dual-supervisor structure + survivable reset.**

- **SAFETY task**: `TIM6` or `TIM7` update interrupt, **100 Hz**, priority above logging and below the DRDY ISR. It exclusively owns: non-blocking MS5611 reads, `PC0/PC1/PC4/PC5` sampling, the flight state machine, launch/apogee/main criteria, pyro gate arbitration, and updates to the `.noinit` flight record. **The IWDG is fed only at the end of a complete SAFETY pass.**
- **Key qualification (without it the kill chain just moves from the IMU to the barometer)**: the feed condition is **control flow completing**, **never any I/O succeeding**. Every peripheral transaction in a SAFETY pass must be non-blocking with a hard timeout, and **a timeout is a normal exit** that marks that sensor invalid and lets the pass finish normally. The invariant goes into the specification: *a SAFETY pass must complete in bounded time under any peripheral behaviour.*
- **Shorten the period from ≥ 2 s to ~400 ms** (PR = /4, RLR ≈ 3200, checked against the fast LSI corner). The original ≥ 2 s tolerated slow logging, which is no longer on this path. The real reason to shorten it is **V-3**: with a gate stuck on, the IWDG period is the FET's last thermal protection (2 s × 6.81 A = 93 A²s, enough to destroy the FET and blow the shared fuse). At 100 Hz, 400 ms still leaves 40 passes of margin.
- **Start the IWDG in software** (option byte left in software mode), and **only after the SAFETY task has completed its first tick**. Reason: hardware start + an IMU/flash that never comes up = an endless reset loop in the air. *(ST's own HAL header contradicts itself on the polarity comment for `OB_IWDG1_SW`; check against RM0433 before programming.)*
- **CONTROL supervisor**: the DRDY ISR only increments a counter; SAFETY checks it every pass. No advance for 25 ms → `IMU_STALL`: servos to 1520 µs centre, then PWM off, roll control off, switch the apogee vote set, set the flag, log, annunciate, up to 3 bounded re-initialisations (1 s apart), then structural removal (swap a function pointer for a stub, not an `if` every cycle). **An IMU stall never resets the MCU.**
- **DRDY rate limit**: > 1.2 kHz of edges within 100 ms → mask the EXTI and let the SAFETY task poll the IMU instead. This removes the silent mode in 2.1(e).
- **Enable HSE CSS** (F-2). A second entry point fully independent of the IMU, and the new watchdog cannot save it either (the timers grow on the same dead clock tree).

### 2.3 Rule text replacing §7.4 (paste directly into the specification)

```
§7.4' Pyro arming, reset recovery and the safe state

7.4'.1  The first instructions after reset (after clock init, before anything else, in this order):
        a) Configure PE4, PYRO2_GATE and every sentinel pin as push-pull outputs driven low (GPIOE->BSRR);
        b) Read RCC_RSR into the flight record, then write RMVF; classify in the order
           PORRSTF → BORRSTF → IWDG1RSTF → WWDG1RSTF → SFTRSTF → LPWRRSTF → PINRSTF.
           (STM32 internal resets also pull NRST low, so PINRSTF can be set together with other flags;
            hence the ordering. This behaviour was not re-checked against RM0433 and is used only for
            log classification, never in any arming criterion.)
        c) The pyros are DISARMED at the instant of reset and stay DISARMED until the criterion in
           7.4'.4 has been evaluated.

7.4'.2  The flight record lives in a .noinit section in the linker script (AXI SRAM or SRAM4),
        not in BKPSRAM. Reason: VBAT is copper-tied to VDD (§3.1 pin 6), so BKPSRAM has no retention
        advantage over ordinary SRAM, yet adds two silent failure points (PWR_CR1 DBP / BKPRAMEN).
        SRAM contents are not cleared by any reset, so the record survives IWDG/software/NRST/BOR
        resets and disappears only on a real power loss — exactly the semantics needed.
        Adding a VBAT coin cell or LSE to "improve retention" is forbidden: it would let a stale
        "in flight" record survive into the next pad session, turning reset recovery into a pad hazard.

        Record format (double-buffered, each copy with its own CRC32 and incrementing sequence number,
        so a reset halfway through a write cannot destroy both):
        magic | version | seq | power_session_id | state | flags | rcc_rsr | reset_count |
        t_since_launch_ms | pad_pressure_pa | agl_max_m | agl_now_m | vspeed_now |
        flight_proven | fired_mask | fire_attempts[2] | pullpin_edge_seen | crc32

        power_session_id is derived from the reset cause: POR or BOR always starts a new session and
        invalidates any inherited record. This closes the path "a phase word left by the previous
        flight/test is inherited after a reset on the pad".

7.4'.3  Non-volatile phase log: an append-only phase log in a pre-erased reserved W25Q128 sector,
        each entry ≤ 32 bytes with this flight's nonce, a sequence number and a CRC, **written only
        on phase transitions** (ARMED / LAUNCH / BURNOUT / APOGEE / FIRE1 / FIRE2 / RESET / LANDED);
        at boot take the last valid entry.
        pad_pressure_pa and the configuration are written **at the ARM instant**, not at launch
        detection — launch detection is the moment of maximum vibration and current in the whole
        flight, the worst possible moment to start a flash transaction.
        The sector is pre-erased on the bench and never erased in flight. A failed write only sets
        a flag and never blocks anything.

7.4'.4  Post-reset arming criterion — only live evidence measured after lift-off.
        In flight, no sense circuit may veto arming or firing:
        ARM_SENSE, PULLPIN and VBAT_SENSE are only logged and annunciated in the air.
        (If ARM_SENSE really is 0, commanding a fire draws no current anyway; if the divider
         resistor has cracked, commanding the fire as usual saves the rocket. On the ground these
         three are hard refusals, because refusing on the ground is free.)

        Condition B (record survived): magic/version/CRC/sequence valid, power_session_id matches
                 this session, state ∈ {BOOST, COAST, DESCENT}, t_since_launch_ms < 600000,
                 and the baro altitude measured after boot is more than 100 m above the stored pad
                 reference.
        Condition C (record lost, i.e. a real power loss): within a 500 ms window after boot,
                 (i) a sustained baro descent rate |v| > 30 m/s for 500 ms, or
                 (ii) free fall |a| < 0.3 g for 300 ms.
        **No gyro criterion** (hand rotation easily exceeds 60 °/s).
        **No "pressure stable / vertical speed near zero" criterion** (a rocket lying in the
        grass satisfies it too).

        B holds → restore phase, t_since_launch, pad_pressure, agl_max and fired_mask; continue flight.
        Only C holds → enter DESCENT_UNKNOWN, arm, and **run no apogee vote** (see 7.4'.5).
        Neither holds → treat as on the pad and follow the normal ground arming procedure.

7.4'.5  DESCENT_UNKNOWN behaviour (by definition the rocket is past apogee, so apogee logic is
        meaningless and dangerous): the only action is descent-based: if a sustained baro descent
        rate > 30 m/s lasts 0.5 s and the drogue channel has not fired, fire the drogue channel
        immediately; then, if the pad reference can be recovered from flash, fire the main by AGL,
        otherwise fire the main at "drogue fire + t_main_nominal".
        If **no sustained descent is measured** within the specified window after entering this
        state, disarm permanently and alarm continuously.
        Sound the alarm tone continuously for the whole time in this state.

7.4'.6  More than 3 resets in one continuous flight → MINIMAL mode: QUADSPI logging off, GNSS off,
        USB off, TIM5/servos off; only barometer + IMU + pyros + buzzer remain.

7.4'.7  Fired flags: a channel with its fired_mask bit set must not fire again unless its CONT
        still reads closed. When fired_mask is unknown, treat every channel as unfired — one extra
        pulse into a burnt bridgewire is harmless, one missed pulse is the vehicle. CONT must be
        read together with ARM_SENSE:
        ARM_SENSE ≈ 0.764 V and CONT ≈ 0.764 V = bridgewire present;
        ARM_SENSE ≈ 0.764 V and CONT ≈ 0 V = already fired or bridgewire missing;
        **with ARM_SENSE ≈ 0, CONT carries no information and must never be used to set a fired
        flag** (plug out, blown fuse and a loose terminal all make both CONT lines read 0).

7.4'.8  The in-air boot path must be a separate code path from the pad boot path, selected in
        the first microseconds by RCC_RSR + the record. The in-air path skips flash erase, GNSS
        configuration, long self-tests and USB enumeration, and **never runs any self-test that
        drives a pyro gate**.
        Budget and measure: reset to "able to evaluate the apogee criterion" ≤ 250 ms, listed as an
        acceptance test (one MS5611 OSR4096 conversion is 9.04 ms; two or three samples for vertical
        speed make the budget achievable, but it must be measured).

7.4'.9  Landing: baro altitude stable within ±3 m for 10 s **or** |a| within 1 g ±0.3 g and
        |ω| < 5 °/s for 10 s **or** more than T_max since launch — any of these enters LANDED:
        drive both gates low, set a software latch that only a power-off can clear, write a LANDED
        log entry, stop the 800 Hz loop and logging, and switch the buzzer to locator mode.
        The landing criterion must require **stable altitude**, not "slow descent", and must enforce
        a T_min floor, or a misjudgement under canopy would inhibit the main.
```

### 2.4 Why this is safe on the pad

- Every physical quantity in the criterion is **unreachable** within human reach: a 100 m altitude difference, a sustained 30 m/s descent, sustained 0.3 g free fall. The two deleted criteria (gyro rotation, stable pressure) are exactly the reachable ones.
- **Arming ≠ firing.** When condition B holds a real apogee decision is still required; when condition C holds the only action requires a sustained 30 m/s descent. And during handling the ARM link is physically unplugged anyway.
- The comparison with today is asymmetric: **under the current rule one fault (an IMU hiccup) is total loss; under the new rule an inadvertent fire on the pad needs a forged record + a physically impossible measurement + a wrong apogee decision — three independent failures.**
- The record vanishes on a real power loss (VBAT = VDD), an **accidental virtue** of this design that must be written down and protected as a safety decision (F-17).

---

## 3. Redundancy architecture

### 3.1 The layered picture

| Layer | Content | Covers | Does not cover |
|---|---|---|---|
| **Hardware (on board)** | Two pyro channels; one IMU providing two votes, one barometer providing one; `PC0/PC1` are ADC123 channels, so ADC1 and ADC3 can read them and cross-check | Open/dud igniters, a single open FET; a single ADC peripheral/calibration fault | **Everything shared upstream**: battery, reed switch, Q1/Q2, RAW, ARM plug, 5 A fuse, PYRO_BUS, buck, 3V3, MCU, firmware image, L2/3V3A, the baro bay. The dual ADC read shares VREF, so it is useless against V-4 |
| **Firmware** | Dual supervisors (SAFETY 100 Hz + CONTROL); cross-reset phase recovery (`.noinit` + flash log); per-sensor degraded modes; 2-of-N apogee vote; descent-rate backup for the main; timer fallbacks; fire-result verification and cross-channel escalation | Sensors stalling/lying, resets, power loss, a blocked static port, drogue failure, single-channel fire failure | A dead MCU, dead power, defects in the firmware itself |
| **Procedure** | **A permanently fitted independent commercial altimeter** (own battery/switch/igniter/charge); **a permanently fitted independent GPS tracker**; a pad checklist; harness standards; per-wire DMM check of the terminals; ground ejection tests | **Everything** the two layers above leave: MCU, buck, battery, switch, fuse, firmware defects, L2 | The shared vents and av-bay (V-8); shared shear pins, shock cord and parachutes |

### 3.2 Independent backup altimeter: permanent, not "first flight only"

**Ruling: permanent.** The reason is not conservatism: V-10 and V-4 cannot be covered by any on-board means, the firmware will change between flights, and this rocket carries a roll-control loop that has never flown — which can fly the rocket off course by itself.

**The definition of independence must be hard-coded** (it is the definition in TRA L3 certification and IREC DTEG §6.9.1, worded the same in both: "completely separate systems, including batteries, switches, avionics, and energetics"; DTEG §6.9.2 also states explicitly "A dual pole switch does not satisfy the requirement for redundant arming switches"):
- Its own battery, its own arming switch, its own igniter, its own charge well.
- **The two altimeters never share one igniter** — one altimeter's fire current would return through the other's output stage.
- Two charges in one well is standard and acceptable; **the two charges for the same event must be staggered** (the AltusMetrum manual: "it's often important to ensure that multiple apogee charges don't fire at precisely the same time, as that can over pressurize the apogee deployment bay and cause a structural failure of the air-frame"; its Redundant Apogee mode staggers by 2 seconds by default).

**The honest cost, to be settled now**: rev G §7.2 closes the whole av-bay with **+1.558 mm of radial margin** (the binding item is the plugged servo header), §7.3-2 makes a battery width ≤ 36 mm a hard constraint, and §7.3-3 finds the terminals cannot be tightened inside the airframe. **Adding another altimeter + battery + switch hole + two charge wells is not "one sled position"; it means a longer coupler, a separate bay section, or a 4 in airframe.** That is a vehicle-level decision and must be made before fab, or this "must" will be quietly dropped at assembly — the worst outcome of all.

**Channel roles (§7 never says whether this rocket is single- or dual-deploy — the biggest open item in this review)**:
- If **dual deploy**: on this board ch1 = apogee/drogue, ch2 = main, and all redundancy comes from the commercial unit. Then **the board has zero redundancy for either event**, and the backup altimeter goes from "should" to "no fly without it".
- If **single deploy**: ch2 is free on-board deployment redundancy — fire ch2 **unconditionally** 2.0 s after ch1 is commanded (do not gate it on "whether ch1 succeeded", which is unobservable), and size both charges for simultaneous firing.
- **If the backup altimeter is not flown on a given flight, this board must be reconfigured as single deploy with both channels on apogee. Never fly dual deploy on a single-string board.**

### 3.3 Items deliberately not made redundant, and why
| Not done | Reason |
|---|---|
| **A second barometer** | Both chips would share the same bay, the same vents, the same 3V3A, the same I2C1 and the same driver. The dominant barometer failure in this field is "the bay pressure is wrong", not "the chip died" — the two would **read wrong together**. Spend the money on vent workmanship and the backup altimeter |
| **A second IMU** | It buys back a ④ (roll control), while ② is still being bought with free firmware. Wrong spending order. AltusMetrum's flagship TeleMetrum also has one barometer and one accelerometer, and PerfectFlite has one barometer — shipping products get their reliability from system-level independence and mechanical discipline, not stacked on-board sensors |
| **Redundant MCU / voting pair / a second buck** | Same; and a second buck's OR network would introduce a new common-mode point |
| **microSD or a second flash** | Class ⑤. §7's "storage error paths are all non-fatal + logging is a low-priority ring-buffer consumer" is **correct** and must stay as is. Any change trading ② for ⑤ runs backwards |
| **A supply-supervisor hardware clamp on the pyro gates** (like the "disables all outputs when the microcontroller voltage is below 2.7V" on the Blue Raven product page) | It turns a ① protection into a new single point that can **block firing** (supervisor output stuck asserted = neither channel ever fires = ②). This design already has something stronger: the removable fused ARM link is a **physical break** no software state can bypass. If it is ever added, H-1's cold self-test must be extended to "prove the clamp releases", or it is not added |
| **A separate battery for the pyro bus** (leave J4.1/RAW empty and feed PYRO_BUS from an external pyro battery) | **Explicitly rejected.** It deletes a whole layer of physical interlock: today PYRO_BUS is live only when "reed switch closed **and** ARM plug in"; afterwards the ARM plug is the only condition. Worse, it **rebuilds by hand the hazard that §1's S3 ruling removed**: with the board off (3V3 = 0) and the plug in, 8.4 V reaches three ADC pins with VDD = 0 through R14 (10k) / R18 (10k), while §3 says FT/TT pins have `IINJ = −5/+0 mA, positive injection not allowed at all`. And it does not deliver the claimed benefit — fire current still returns igniter → drain → source → board ground plane, so the high-di/dt loop still passes by the MCU and sensors. The energy independence that is really needed lives off the board, in the backup altimeter's own battery |
| **Shortening the fire pulse to 12 ms** | See the rejected items in §4 |
| **VBAT coin cell / LSE** | See F-17. Keeping VBAT = VDD is a safety decision, not a part-saving one |

---

## 4. Hardware change list

> All are schematic-stage changes (the PCB was not yet routed). Baseline: 101 soldered parts / 39 part numbers.

### 4.1 MUST

**H-1 — Cold pull-up on the pyro drains + reverse blocking. `+2 × 47 kΩ 0603` + `1 × BAT54A SOT-23`.**

Connection: `3V3 → BAT54A common anode; cathode 1 → 47k → PYRO1_OUT; cathode 2 → 47k → PYRO2_OUT`.

- **Covers**: I-1 (FET short, completely untestable today, where the only "test" is inserting the plug and seeing whether it goes off), open FETs, a **cold** reading of igniter present/open, ADC channels stuck at zero, and makes the I-2/I-3 bridges testable. It turns §7's "FET short self-test", **which cannot be implemented on this hardware**, into a real four-state measurement.
- **Values (ARM plug out, both gates low, 3V3 = 3.3 V, solved simultaneously with R14/R15, R18/R19, R22/R23 all 10k/1k; the three ADC nodes are **one** resistor network and must be read jointly, not channel by channel)**:

  | PC5 (ARM_SENSE) | PC0 | PC1 | Reading |
  |---|---|---|---|
  | 40.5 mV | 40.5 mV | 40.5 mV | Both igniters present, both FETs healthy (**normal flight configuration**) |
  | 31.4 mV | 31.4 mV | 56.9 mV | Igniter on ch1 only |
  | 31.4 mV | 56.9 mV | 31.4 mV | Igniter on ch2 only |
  | 0 | 56.9 mV | 56.9 mV | No igniter on either channel |
  | 0 | 0 | 0 or 56.9 mV | **At least one FET shorted / drain shorted to ground → continuous tone, refuse everything, do not touch the ARM plug** |
  | Any > 100 mV | | | Pull-up part or divider damaged → continuous tone, refuse to arm |

  Adjacent states differ by 16.4–25.5 mV; a 16-bit LSB is 50.35 µV → **326–506 LSB**, ample with oversampling. Bridgewire current **31.4–40.5 µA** (not 62.9 µA — the pull-up current splits between the drain's own 11k divider and the 11k through the bridgewire), 19–24× below the 0.764 mA armed-state test current already accepted today.
- **Active half (optional but strongly recommended)**: with the plug out, drive each gate high for 10 ms in turn; CONT must collapse to ≈ 0 mV and then recover; no collapse = 470R open / gate bond broken / FET open. The current through the bridgewire during this comes from the other channel's pull-up, about **70 µA** (not zero). This is the **only** way in the whole design to verify the firing path end to end.
- **New failure mode introduced**: **a shorted pull-up resistor is class ①.** Without the BAT54A: with the ARM plug in, the drain is clamped to 3.3 V, 5.1 V appears across the bridgewire, and at rev G's mandatory ≥ 1.0 Ω that is **5.1 A → immediate fire**. The BAT54A is there to remove exactly that: with the drain at 8.4 V above the 3.3 V anode, the diode is reverse-biased and the path is fully open (reverse leakage at the µA level, flowing from the drain into 3V3, which can fire nothing). The diode's forward drop lowers the cold-test source to about 3.1 V, scaling the table down by 6 %; calibrate once on the bench. Vf's temperature drift maps to about 1.5 mV at the ADC nodes, acceptable. **The diode itself open** = cold test reads all zeros = false "FET short" = scrub the flight, which is the safe direction.
- **Cost**: +3 parts, +1 part number (47k is already R4's part number; the BAT54A is new, but it is the same family prepared for the pull-pin clamp in frozen §8 item 6). The layout must stay out of rev G §4's Z2 high-current corner.

**H-2 — Separate the two pyro gates and surround them with sentinel pins. Zero parts.**

- Today: `PE3 = LED_RED (2) / PE4 = PYRO1_GATE (3) / PE5 = PYRO2_GATE (4) / PE6 = BUZZ_GATE (5)`.
- Change to: `PYRO1_GATE = PE4 (pin 3)` unchanged; `PYRO2_GATE → PE13 (pin 43)`; `LED_RED → PE8 (pin 38)`; `BUZZ_GATE → PE15 (pin 45)`. **`PE3 (2), PE5 (4), PE6 (5), PE12 (42), PE14 (44)` are all configured as push-pull outputs permanently driven low and connected to no net on the PCB**, as sentinels. A solder bridge onto a sentinel only pulls the gate low.
- **Do not** put the buzzer on pins 97/98: they are next to `pin 96 = PB9 = I2C1_SDA`, which would aim a 2.7 kHz square wave at the deployment-critical sensor bus. And **do not** add sentinels only on the outside while leaving the two gates adjacent (I-3 is not protected by any outside sentinel).
- **New failure mode introduced**: a bridge between `PE2 (pin 1) = QSPI_IO2` and the `PE3` sentinel shorts a high-speed flash data line onto an output driven low and kills QSPI logging — **exactly the intended trade: a ① hazard exchanged for a ⑤**. Also, 5 GPIOs are permanently spent "doing nothing" (about 40 remain free), and a careless GPIO initialisation sweep would silently remove the sentinels → the sentinel configuration must live in the same function that drives the pyro gates low.
- **Must check**: whether `PE13/PE15` are in the H743 bootloader list of AN2606 Table 113 (PE pins usually are not, but this is **marked unverified**), and whether their reset state has no pull. Note `PE4 = TIM1_CH3N? / PE13 = TIM1_CH3 / PE5 = TIM15_CH1 / PE4 = TIM15_CH1N` — however they are arranged, the pyro gates land on timer AFs, so the accompanying firmware rule F-16 (never enable the RCC clocks of TIM1 and TIM15 + lock PE3/PE4/PE5/PE6/PE12/PE13/PE14 with `GPIOE->LCKR`) is **mandatory**.

**H-3 — Restore the QSPI /WP and /HOLD pull-ups. `+2 × 10 kΩ` (`C25744`, already used 13 times, zero new part numbers).**

- Covers V-13. The part ships with `QE = 0`, so the JEDEC ID read, the three status-register reads and the write that sets QE are all single-line transactions during which QUADSPI does not drive `PE2/PD13`. §1's deletion argument ("driven data lines in 4-bit mode") only holds after QE is set, and **the self-test itself runs before that**.
- New failure mode: two more solder joints and a little capacitive load on two QSPI data lines; irrelevant on 20 mm traces.

**H-4 — Add a pull-down on `VBUS_SENSE (PD15)`. `+1 × 100 kΩ` (already R3/R1's part number).**

- Today `VBUS_SENSE = {R9.2, U1.62}`, R9 = 100k to VBUS, **no pull-down**. Both configurations are broken: with no internal pull, after unplugging PD15 is a truly floating CMOS input that drifts anywhere (→ may enable the OTG stack in flight, exactly what §7.11 prevents, and may cause a false "USB present → refuse to arm" scrub); with the internal pull-down (30/40/50 kΩ on the H7), a plugged cable reads only `5.0 × 40 / 140 = 1.43 V`, below the FT input VIH ≈ 1.79 V → **USB is never detected**.
- Add 100k to ground and force `PUPDR[PD15] = 00`: 2.50 V plugged (still 2.20 V at USB's 4.40 V minimum), a hard 0 V unplugged. The divider also halves VBUS overvoltage events on a pin limited to 7.3 V.
- New failure mode: none. But **the external pull-down only works with the internal pull disabled**; both together give 1.11 V and reproduce the failure.

**H-5 — Rule on the J-ARM pin definition + split PYRO_BUS into two independently fused buses. Zero parts on the board.**

- V-17 must be ruled first (netlist vs rev G §3.3). Also fix V-5: split `PYRO_BUS` into `PYRO1_BUS` (carrying R14's ARM_SENSE divider) and `PYRO2_BUS`, make the 6-pos terminal `RAW_A / PYRO1_BUS / PYRO1_OUT / RAW_B / PYRO2_BUS / PYRO2_OUT`, and make the removable arming plug a four-wire, two-fuse part (RAW_A → F1 → PYRO1_BUS, RAW_B → F2 → PYRO2_BUS).
- **Covers**: a shorted igniter on one channel no longer kills the other (today it necessarily does).
- **Cost**: zero board parts; +1 fuse holder in the plug; ARM_SENSE can only see the ch1 bus (ch2 bus visibility comes from H-1's cold test and the CONT readings).
- **New failure modes**: a stray strand between `RAW_A/RAW_B` and the adjacent BUS position is still I-4, now in two places; the plug gains two more contacts in a 30 g environment, and an intermittent contact = no deployment. **If not adopted**, the document must say in black and white "the two pyro channels are not redundant against anything upstream", and the backup altimeter is promoted from "should" to "no fly without it".
- **Do not** lower the fuse rating: a normal fire is 20 ms × 6.81 A = **0.93 A²s**, while a blade fuse's melting I²t is tens of A²s — a normal fire does not threaten it at all. The real threats are shorts (V-5) and a gate stuck on (V-3).

**H-6 — Rule on the physical form of the ARM link (V-18). Zero parts on the board; a vehicle-level decision.**

Pick one of two, now:
- (a) Run a short pigtail from J-ARM's RAW/BUS positions to a connector outside the airframe **with positive locking, keying and strain relief**, treated as flight hardware (pull test + checklist item + Remove-Before-Flight streamer). New failures: yanked off by the harness at 30 g = both channels dead; chafing on the airframe wall = I-4.
- (b) Accept that the ARM link is already in when the airframe is closed and the reed switch is the only pad interlock. Then **the T-1 bench test, a continuous power-on heartbeat tone and F-14's negative ARM_SENSE check are upgraded from "recommended" to "mandatory"**, because no physical break is within human reach any more.

### 4.2 SHOULD

**H-7 — `R2` from 10 kΩ to 1 kΩ. Zero parts.** Switch current 76 µA → 760 µA, out of the oxide-film regime of non-hermetic contacts; also improves `Vgs` from −7.64 V to −8.32 V @ 8.4 V (AON6403 Vgs absolute max ±20 V, safe). New failure: the turn-off gate charging constant changes very little (the turn-off path is still R1's 100k alone); no material effect.

**H-8 — Unidirectional TVS (SMAJ18A class) on each pyro drain ×2. +2 parts, +1 part number.** Covers EMI injected into the MCU/sensors by the 36 V fast edge at the fire instant (V-3, and the highest-probability entry to the kill chain: "your own first charge resets you"). **The variant "reuse the BOM's SS34 from drain to bus" is explicitly rejected**: the SS34's reverse leakage is already hundreds of µA at 25 °C and rises about an order of magnitude every 25 °C, while the whole continuity test runs on only 0.764 mA — in a sun-baked airframe it would pull an **open** igniter to a "healthy" reading, turning a detected failure into an undetected one, which is disqualifying by this document's criteria. New failure: a shorted TVS = that drain permanently grounded = that channel cannot fire; H-1's cold test must cover it, so H-1 must land first.

**H-9 — A 1 µF/50 V 0603 (`C15849`, zero new part numbers) from `GATE_SW` to the common-source node (**not** to ground). +1 part, rated "consider".**
- Existing bounce immunity is already ~1 ms (the gate charges through R1's 100k from −7.64 V to the worst-case −2.2 V threshold in about 0.95 ms) plus 12.5–18 ms of logic-side hold-up; reed **contact bounce** is already covered. This capacitor raises immunity to about 124 ms, aimed at **magnet-shift-class long opens**.
- The direction must be gate-source, not gate-ground: a shorted gate-source capacitor → Vgs = 0 → FET off → board dead on the bench (safe direction); a shorted gate-ground capacitor would **lock the board permanently on**, which is class ①.
- Cost: about 124 ms of power-off delay — "flip the switch" and "confirm power is off" no longer happen together, so the procedure must change to confirming silence and no lights. X5R loses 20–35 % at 8.4 V DC bias; recompute the "124 ms" with the real capacitance.
- **Note that rev G §5.7 already overturned the 99 A hot-plug inrush** (the gate network's 9.091 kΩ Thevenin × Ciss 6100–9120 pF → τ 55–83 µs is itself a soft start), so **do not** use "inrush suppression" as a reason again.

**H-10 — BAT54S clamp on the pull-pin to 3V3/GND. +1 part (same family as H-1).** Closes frozen §8 item 6. §8 thought the 1k series resistor was enough, but the arithmetic: with a chafe onto 8.4 V the only path is the 10k pull-up, and the pin sees `3.3 + 5.1 × 10 / 11 = 7.94 V`, above the 7.3 V absolute limit, and H743 FT pins have **no** clamp diode to VDD. No resistor change alone works (withstanding it needs > 2.76 k, reading a low needs < 4.0 k, with no usable margin at either end). New failure: a shorted BAT54S pins PD14 to a rail → covered for free by the checklist item "PULLPIN must change state when the pin is pulled".

### 4.3 Explicitly rejected

| Rejected | Reason |
|---|---|
| **Shortening the fire pulse from 20 ms to 12 ms** | Trades ② for ⑤, exactly the backwards trade this document forbids. The fuse is not at risk at all (0.93–1.41 A²s vs tens of A²s). A cold, high-resistance, badly crimped igniter needs **more** energy. For comparison, the Blue Raven's default output duration is **1.0 second**; this design is already 50× shorter than a shipping product — the thin side is this one, not the other. If it changes at all, the direction is **longer**, to 25–30 ms after checking against the AO3400A's transient thermal impedance (rev G's 25 ms hard abort is the upper bound) |
| **Cutting the RAW → J4.1 copper and using an external pyro battery** | See §3.3. Deletes a physical interlock + rebuilds the S3 hazard + the claimed decoupling does not materialise (the return still runs through the board ground plane) |
| **A software-controlled high-side series switch on the pyro bus ("two switches in series", textbook style)** | This design already has a **stronger** series break: the removable fused ARM plug, physically open and impossible for software to bypass. A software-controlled series switch will be stuck closed exactly when it most needs to be open, while introducing a new common-mode blocking point for **both** channels (① traded for ②) |
| **Second barometer / second IMU / redundant MCU / microSD** | See §3.3 |
| **VBAT coin cell or LSE** | See F-17 |
| **BOR at Level 2/3** | See F-3 |

**Net hardware additions (MUST items): +6 parts (47k × 2, BAT54A × 1, 10k × 2, 100k × 1), +1 part number (BAT54A).** Against 101 parts / 39 part numbers that is **+5.9 % placements, +2.6 % part numbers**. All 0402/0603/SOT-23, about 15 mm² in total, placeable between the MCU and the pyro block in the y 34–46 zone (**not in rev G §4's Z2 high-current corner, which has only 0.20 mm left**).

---

## 5. Firmware rules (replacing / revising frozen §7)

> Imperative, each ready to go into the specification. Those with a § number state what they replace.

**F-1 (replaces §7.1)** Two loops, two clocks. Roll control stays in the 800 Hz DRDY ISR (the sensor's clock). **Launch detection, apogee detection, main detection, pyro arbitration, the flight record and IWDG feeding all move to a 100 Hz SAFETY timer ISR (TIM6/TIM7)**, consuming whatever sensor data is currently valid. The IWDG is fed only at the end of a complete SAFETY pass, **conditioned on control flow completing, not on any I/O succeeding**. Period ~400 ms. A SAFETY pass must complete in bounded time under any peripheral behaviour. No code path may disable interrupts for more than 20 µs; no ISR may busy-wait without a bound (always bounded with the free-running TIM2 microsecond timebase that §7.3 reserves). The flight-state structure shared between the loops uses single-writer discipline + seqlock snapshots.
- *New failure*: the IWDG no longer proves the roll loop is alive → a hung roll loop now only silently loses roll control (④) instead of resetting (②). This is a **deliberate trade**, but it means the CONTROL supervisor, its logging and its tones are now safety-related code and must be tested as such. A defect in the SAFETY task itself becomes the watchdog's new single point → that function must be short, allocation-free, simply branched, and unit-tested on its own.

**F-2 (new)** Enable `RCC_CR.CSSHSEON`. Put a timeout on the HSE-ready wait at boot, falling back to HSI. NMI handler: switch to a known HSI clock tree **and recompute every safety time constant** (200 → 64 MHz stretches a 20 ms pulse to 62 ms, a 333 Hz servo frame to 104 Hz, and every timer by 3.1×), set `CLOCK_DEGRADED`, log, annunciate, **keep flying, never reset**. Also cross-check the timebase for free in flight: TIM2 counts against the LSI-derived IWDG interval and against MS5611 conversion completion (OSR4096 8.22 ms typ / 9.04 ms max).

**F-3 (new)** Option byte `OB_BOR_LEVEL1` (ST's own `stm32h7xx_hal_flash_ex.h`: LEVEL0 1.6 V / LEVEL1 2.1 V / LEVEL2 2.4 V / LEVEL3 2.7 V; **exact rising/falling thresholds and hysteresis not checked against DS12110**). At every boot compare `FLASH_OPTSR_CUR` with the compile-time expectation and refuse to arm on mismatch (option bytes can be silently changed by a debugger session or a full erase). **Do not use Level 2/3**: that would turn survivable voltage dips into resets, trading ⑤ for ②. The cost of Level 1 is the W25Q128 (2.7 V minimum) running out of spec in the last 600 mV → covered by F-12's write inhibit. Also enable `PVD @ 2.85 V (VDD)` and `AVD @ 2.8 V (VDDA)`, each with hysteresis and a minimum re-trigger interval to prevent interrupt storms; **the PVD handler must not abort a fire pulse already more than 8 ms in** (a half fire is worse than no fire).

**F-4 (replaces §7.4)** Full text in §2.3.

**F-5 (new, revises §7.3)** Roll control ends at **burnout + margin**, not at apogee — the mission objective ends with the motor, and continuing to actuate only pollutes V2's velocity integral (the centripetal component on an off-axis accelerometer) and eats into the fire energy budget. 200 ms before any fire command: write **1520 µs** to all four (the HV6120's centre, not 1500 and not 0), stop PWM 200 ms later, and hold until 200 ms after the pulse.
- **Must be measured on the bench**: both official MKS pages return 404, and **no document says** whether the HV6120 holds its last position (at full torque) or goes limp with no signal. If it holds, `CCR = 0` neither unloads the current nor centres, and the whole §7.2 argument that "a servo line defined low after reset = safe" loses its basis. Method: load to an end stop, remove the signal, record holding current and whether it releases, and write the answer into §7.
- Servo stall detection: command near centre while `VBAT_SENSE` stays depressed for > 1 s → `SERVO_STALL`, drive PA0–PA3 low (held by the 10k pull-downs), log, annunciate. Absolute roll-rate limit |p| > 600 °/s → freeze the integrator, **centre immediately and give up roll control**.
- **Explicitly rejected: "command full opposite deflection when the gyro saturates"**: one possible cause of saturation is a reversed control sign, and commanding full deflection at maximum dynamic pressure on a clipped measurement escalates ④ to ②.

**F-6 (new)** A `LIFTOFF` latch is a **hard precondition on every firing path**, checked in ISR context alongside the ARM_SENSE and CONT checks, never cleared for the whole flight. Set when `(axial acceleration > 3 g for 100 ms)` **OR** `(when IMU_VALID is false: AGL > 30 m and climbing > 15 m/s for 200 ms)`. If both hold within 500 ms, also set `LAUNCH_CORROBORATED` (only that allows the timer fallback to act). **"Sustained" is the key**: a knock is a < 20 ms event.
- Also set a monotonic `FLIGHT_PROVEN` latch: `AGL_max ≥ 100 m` (relative to the pad reference) **or** a peak integrated velocity > 50 m/s. **It gates the entire apogee decision.**

**F-7 (new)** The pull-pin is advisory only: it only gates the ground `PAD_ARMED → READY` transition, must **witness** a LOW → HIGH transition (high at power-up = a fault code, not a permission), writes the transition event into the `.noinit` record so a brown-out reset on the pad does not cause a refusal to arm, and is **completely ignored after launch detection**. Log its level every housekeeping cycle.

**F-8 (new)** LANDED definition and behaviour: see 7.4'.9 in §2.3. After landing the buzzer switches to locator mode (300 ms / 5 s), SYSCLK drops, GNSS turns off (or keeps one last-position tone), and a 256-byte flight summary is written to **bank 2** of the MCU's internal flash (execution is from bank 1) — **only when LANDED and disarmed**, with the sector address checked against the linker script at compile time (H743 internal flash has 128 KB sectors and 256-bit words; a naive 256-byte write consumes a whole sector and stalls instruction fetch).

**F-9 (replaces §7.4's "pulse ≤ 20 ms")** **Hardware termination** of fire pulses: at the fire instant, load a dedicated timer whose ISR has the highest priority in the system (above DRDY) and whose only action is writing the clear to `GPIOE->BSRR`; where possible use a timer compare event triggering a DMA write to BSRR instead, so the pulse ends even if the CPU stops. Layer on top rev G §5.6's **independent TIM2-measured 25 ms hard abort**, and the SAFETY task's backstop: any gate high for more than 30 ms → drive both low unconditionally and set a fault. **Only one channel on at any time** is guaranteed structurally by **one single arbitration function** that takes a channel number and asserts the other channel is low before driving; two charges for the same event must be staggered.

**F-10 (revises the last sentence of §7.4, mandatory)** **In flight, ARM_SENSE and PYRO*_CONT are only logged and annunciated and must never veto a fire command.** On the ground they are hard refusals. The asymmetry must be written into the specification: firing into an open/absent bridgewire costs nothing, refusing to fire into a good one costs the vehicle; and both readings hang behind V-4's single inductor.

**F-11 (replaces §7.7)** Apogee detection.

- Per-cycle validity flags. `BARO_VALID` = PROM CRC-4 passed at boot **and** re-verified at arming **and** no I2C error within 200 ms **and** the **raw D1 words of the last 10 conversions not all identical** (**never threshold the engineering value** — pressure naturally stops changing at apogee, so a threshold detector would declare it dead exactly when it is needed; at OSR4096 real noise is several LSB of the 24-bit word, so bit-identical words are practically impossible) **and** D2 refreshing **and** 10–1200 mbar **and** |dP/dt| < 500 mbar/s **and** not within 500 ms after any fire. `IMU_VALID` = the DRDY count advancing **and** WHO_AM_I (register 0x72 → 0xE9) re-verified at 10 Hz **and** configuration registers read back consistently at 1 Hz **and** the noise floor in bounds (`σ_a ∈ [0.5, 20] mg`, `σ_g ∈ [0.02, 2] °/s`; TDK's published 70 µg/√Hz and 3.8 mdps/√Hz predict 1.40 mg / 0.076 °/s at 400 Hz bandwidth; **below the lower bound is the danger sign** — it means the sensor is not sampling at all).
- Three votes. **V1 baro** = the filtered altitude has fallen ≥ 3 m from its running maximum for 200 ms, |v| < 100 m/s (transonic lockout), `BARO_VALID`, and that running maximum corresponds to AGL ≥ 100 m. **V2 acceleration** = the vertical velocity from integrating acceleration alone crosses ≤ 0 **after having exceeded 50 m/s** (a **crossing**, not a level — the level is always true at rest), `IMU_VALID`, and saturation occupied ≤ 5 % of boost. **V3 tilt** = gyro-integrated tilt > 90°, `IMU_VALID`, `FLIGHT_PROVEN`, burnout + 1 s.
- Global gate: `LIFTOFF` ∧ `FLIGHT_PROVEN` ∧ apogee lockout elapsed ∧ burnout + 0.5 s. **Apogee lockout = min(configured value, 0.5 × simulated apogee time), with no fixed 3 s floor** — a low-impulse / under-performing flight reaches apogee in 4–6 s, and a fixed floor would push the drogue into the fast segment after apogee. The real transonic defence is the velocity lockout (conditional, degrading gracefully on off-nominal trajectories), not time.
- Fire: `(V1 + V2 + V3) ≥ 2` (a majority of valid votes), latched until the end of flight. **For any apogee decision earlier than 60 % of the nominal apogee time, V1 must be one of the votes** — the barometer is the only sensor an inertial fault cannot fool, and early deployment is the destructive direction.
- **A velocity lock that overrides everything**: with estimated velocity > 100 m/s, **do not fire the apogee charge**, whatever the votes. This is needed because V3 is **correlated** with this rocket's most likely mission failure: a roll-control instability can take tilt past 90° while the rocket is still fast, and correlated failure of two votes is exactly what a voting architecture must not have.
- Acceleration saturation handling **replaces §7.6's intuition**: `|a| ≥ 32 g` **is positive evidence that thrust is still on; it must keep the gate closed**, not open it. Only saturation lasting longer than 1.5 × the credible burn time for that motor class is judged a fault (only then does it open on "fail permissive"). Saturation invalidates V2 but **does not affect V3** (axial saturation has nothing to do with the gyro).
- Degradation rules: `IMU_VALID = false` (V2 and V3 **live and die together** — same chip, same SPI, same 3V3A) → V1 alone, with a tightened criterion (fall ≥ 5 m for 400 ms, |v| < 60 m/s). `BARO_VALID = false` → V2 ∧ V3; if acceleration saturated, V3 + timer fallback; here **§7.7's "the accelerometer must not be promoted to primary apogee source" must give way** — a blocked vent is the most common real deployment failure in this field, and if the inertial votes can never be promoted that failure has no solution. Also strengthen the dead-baro criterion to "pressure has risen ≥ 150–300 Pa from its running minimum and held for 300 ms" (a transonic dip falls back and drops again; a real apogee does not). Both failed → enable the timer fallback **only if `LAUNCH_CORROBORATED` ∧ `FLIGHT_PROVEN`**, firing at the nominal apogee time within [3 s, 60 s]; if launch has only a single source, the timer fallback is **disabled** and the vehicle is left to the backup altimeter. Log the reason loudly.
- Main: apogee latched ∧ apogee fire + 1.5 s ∧ AGL < h_main ∧ sustained descent. **Backup main**: apogee latched ∧ baro descent rate > 60 m/s for 1 s → deploy the main early (drogue failed). With `BARO_VALID` false, fall back to "apogee fire + t_main_nominal".
- Disagreement: exactly one vote true for > 3 s while the other valid votes are false → set `DISAGREE`, log which one, annunciate after landing, **do not fire on it**.
- Continuous re-zeroing of the pad reference: while `LAUNCHED` is false and the rocket is confirmed still (|a| within 0.98–1.02 g, |ω| < 5 °/s for 5 s), slowly track pad pressure; freeze at launch detection. **Write it to flash at the ARM instant.** Reason: rockets typically sit on the rail for 15–60 minutes, and a 4 hPa weather change is 33 m of apparent altitude, and this number feeds both the main altitude and the post-reset arming criterion.

**F-12 (new)** In every SAFETY pass, solve absolute VDDA from `VREFINT` against `VREFIN_CAL (0x1FF1E860)` (§7.9 already reads it, just not as a fault signal). VDDA outside 3.0–3.6 V → `ANALOG_RAIL_FAULT`: mark every ADC-derived value suspect, sound a dedicated tone, **refuse to arm on the ground, never inhibit firing in flight**. This is the only free detector for V-4 (L2); set the trip threshold from one bench measurement with L2 deliberately disconnected. Also: when `3V3A` collapses, the I2C pull-ups `R12/R13` hang on `3V3` (not 3V3A) and back-feed an unpowered MS5611's pins — "IMU + barometer + GNSS lost at once" must be classified as **one** `RAIL_DEAD` code, not three independent faults. VDDA < 3.10 V: stop starting new flash page programs; < 3.00 V: abort logging for 500 ms and flag it (the declared cost of choosing BOR Level 1).

**F-13 (new)** Fire-result verification and escalation. During the pulse, burst-sample `PYROn_CONT`, `ARM_SENSE` and `VBAT_SENSE` at ~10 kHz (100 Hz gives only one or two samples in 20 ms, not enough). Success signature: the drain collapses toward 0, the bus sags moderately, and CONT reads **open** within ~100 ms after the pulse (bridgewire burnt). Failure signatures and responses: (a) the drain doesn't collapse and the bus doesn't sag → FET not conducting or igniter resistance too high → retry; (b) CONT still closed after 100 ms → bridgewire not burnt → retry; (c) **the bus collapses hard toward the drain** = short signature → **never retry** (a retry pumps 30–50 A repeatedly through the shared fuse and kills the other channel), log, annunciate, and switch to the other channel if configured; (d) `ARM_SENSE` collapses to 0 while `VBAT_SENSE` is normal → fuse/plug/terminal open, both channels void, stop trying. **Limit by outcome, not to a single attempt**: at most 3 pulses per channel, 200 ms apart, stopping as soon as CONT reads open. ("One pulse per channel" is wrong: a pulse cut off by a reset at 5 ms delivers only a quarter of its energy, and the record would then forbid forever the retry that could have saved the vehicle.) Monitor CONT at 100 Hz throughout the flight: a channel going open during boost must **pre-emptively** queue the other channel for the same event.

**F-14 (new)** A **negative** ARM_SENSE check: from power-up until the state machine enters `PAD_ARM_PENDING` (airframe closed, on the rail, operator action expected), `ARM_SENSE < 50 mV` is a precondition for every ground mode. Reading > 0.4 V before that **is a ① hazard, not a state**: latch a continuous tone + solid red LED, refuse every interactive mode, refuse to arm, log. This covers I-4 (stray strand on the terminal), a forgotten plug, and on-board shorts. Likewise, H-1's active gate self-test **may only run** when all of these hold: no valid in-flight record, `ARM_SENSE` read < 50 mV in the same millisecond and re-sampled continuously during the test (abort within one ADC conversion), the pull-pin reading "inserted", and more than 2 s since power-up; the function may run only once per power-up and clears its own entry (function pointer / latch) so that even a wild jump cannot re-enter it. **The cold passive half (all gates low) has no such restriction and runs at every power-up.** Written as a §7 invariant: *apart from a commanded in-flight fire, no code path may drive a pyro gate high while ARM_SENSE is non-zero.*

**F-15 (replaces §7.14)** See §6.

**F-16 (new)** The RCC clocks for `TIM1` and `TIM15` are **never enabled** for the lifetime of the firmware (a peripheral without a clock cannot drive a pin), and after PE3/PE4/PE5/PE6/PE12/PE13/PE14 are configured as GPIO push-pull outputs they are locked with `GPIOE->LCKR` (LCKR freezes MODER/OTYPER/OSPEEDR/PUPDR/AFRL/AFRH until the next reset). **Read back LCKR bit 16 to confirm the lock took**; refuse to arm if not (a wrong LCKR write sequence fails silently).

**F-17 (new; must be written into the frozen document with its reason)** **No VBAT coin cell, no LSE, and this deletion is not to be reopened.** VBAT copper-tied to VDD makes the backup domain disappear together with 3V3, exactly the semantics F-4 needs: the flight record survives a reset but not a real power loss. A coin cell would let a stale "in flight" record live into the next pad session and become an input to the arming criterion. Timekeeping across resets is served by the record's `t_since_launch_ms`, updated at 100 Hz (10 ms resolution, zero timing hardware). The accepted cost: a real power loss in flight loses the phase, and then F-4's condition C and the flash phase log are relied upon — **so both are mandatory, not optional.**

**F-18 (revises §7.6 / new)** SPI1 and IMU recovery (§7.13 gave the backup path's I2C1 a full recovery procedure yet said nothing about **the one bus that can kill the vehicle** — priorities completely inverted): an explicit recovery routine = abort the transfer, disable SPI1, flush the FIFO, clear all error flags, re-initialise, raise then lower CS, re-read WHO_AM_I, reconfigure DRDY; called by the SAFETY task on `IMU_STALL`, bounded in count and logged. **INT1 must be configured in pulse mode, not latched mode** — in latched mode one failed status-register read holds INT1 asserted forever, with no further EXTI edges: a permanent silent stall caused purely by firmware on intact hardware. Also have the SAFETY task poll the IMU's own `INT_STATUS` as a completely interrupt-independent bypass. **Explicitly program `PUPDR[PB4] = 01` (pull-up)**: PB4's NJTRST reset pull-up is gone once it is configured as AF5, and §5.4 also requires disabling the ICM-45686's AP_SDO internal pull-up — without this step an open MISO **floats** instead of reading 0xFF, and the diagnostic "WHO_AM_I == 0xFF" simply does not exist. PUPDR is independent of MODER, a pull-up does not affect SPI at ≤ 24 MHz, and it sits on the **surviving side** of a cracked joint.

**F-19 (revises §7.7 / §7.13)** **No MS5611 I2C transaction may run in DRDY ISR context** (one OSR4096 conversion is 9.04 ms; putting it inside a 1.25 ms ISR is immediately fatal, and a hung bus goes straight to the end of the kill chain). Instead use a non-blocking state machine in the SAFETY task with pipelined conversions (start on tick N, read on tick N+1), lowering the effective pressure rate to 50 Hz if needed to buy 50 % bus headroom (50 Hz is ample for apogee detection). A sample not updated for more than 50 ms is marked degraded, and **nothing ever blocks**. I2C1 recovery (9 clocks + STOP) must be driven by a **timer**, not by the stuck transaction, running in a low-priority context with interrupts enabled; after ≤ 2 attempts declare `BARO_INVALID`. If the spare header is ever populated, an external device must not be able to drag a transaction past the timeout — otherwise use §3.6's own fallback and move to I2C3 (PA8/PC9), permanently giving up SDMMC1_D1 (microSD is deleted and logging is class ⑤, so the trade is worth it).

**F-20 (new)** Storage integrity self-test (run on the bench, not on the pad): JEDEC ID = `EF 40 18`; in **SR1** (05h) BP2:0 / TB / SEC / SRP all 0; in **SR2** (35h) **CMP** and SRL 0; in **SR3** (15h) **WPS** 0. — CMP is in SR2, not SR1, so checking only SR1 reads a reserved bit; and with `WPS = 1` the part switches to individual block locks, **all block lock bits are 1 after power-up and the whole chip is read-only**, while SR1 reads perfectly clean and every page program silently "succeeds" without storing anything. Also: erase-write-read-compare on a dedicated scrub sector; 32 pseudo-random pages of the flight area must all be 0xFF; the erase routine writes an "erase complete" magic and a generation counter **last**. Full-chip erase only on the bench (a W25Q128 chip erase can take 200 s; tying up the pad with it is worse than flying without a log); on the pad, flash faults are always **downgraded to warnings**. After a reset, locate the write pointer by binary search at boot and **never erase**. Log records are packed into full 256-byte pages by a low-priority consumer before programming (programming each 64 B record gives 254 programs/s, 76 % flash duty at the 3 ms worst-case program time; packed, 19 %), and the CRC is also computed on the consumer side. Apart from one single audited "clear protection" routine, nothing anywhere may issue a write-status-register command.

**F-21 (new)** Keep the SOIC-8 clip readback path alive (the only way to get data off a destroyed board): never set the BP/CMP/SRP/WPS/OTP lock bits; with the board unpowered the part must still answer single-line `0x9F` and `0x03` (1-4-4 reads on the H7 side are fine, but confirm by measurement after every QSPI driver change); keep the package on the top side, not shadowed by tall parts, uncoated, with a pin-1 mark on the silkscreen. The log format is public and re-synchronisable (magic, version, fixed-length records, per-record CRC, monotonic sequence number).

**F-22 (new)** Freshness is a property of **every** sensing path, not a special case for the IMU. Every path carries a monotonic sample count and a timestamp, and the SAFETY task checks that they advance at the right rate. The ADC matters most: if its DMA stalls, `PC0/PC1/PC4/PC5` all freeze at their last readings, so every arming precondition passes forever, the continuity trace in the log is a perfect straight line, and F-13's fire verification always "succeeds". Use drifting internal channels (VREFINT, die temperature) as liveness signals: N consecutive byte-identical conversions across the whole sequence is the stalled-DMA signature. Freshness and dropped-frame counters must be logged (even when 0), or a dead consumer cannot be told from a healthy one. Also: `PC0/PC1` are `ADC123_INP10/11`, so ADC1 and ADC3 can read them together and compare, with a persistent difference = ADC fault rather than a continuity change — free, but state honestly that it is **redundant only against peripheral/calibration/configuration faults and useless against V-4** (both instances share VREF+/VDDA).

**F-23 (new)** At every boot write `RCC_RSR`, the reset counter, the recovered record and the reason for every arming decision as a separate record type. **Any reset between launch detection and landing grounds that vehicle until the cause is found**, and the cause must be written down before the next flight. Log whether the three votes agreed on every flight, so a slowly worsening vent or a drifting gyro shows up as a trend rather than on the flight that loses the rocket.

---

## 6. Ground procedures and annunciation

### 6.1 What the buzzer can do (get the physics straight first)

MLT-8530 rated 80 dB @ 10 cm (**the LCSC product page lists no SPL; this value comes from the frozen document and was not checked against the maker's datasheet**). Free field: 1 m → 60 dB, 3 m → 50.5 dB, 10 m → 40 dB, **30.5 m → 30.3 dB**. Site background 45–55 dBA. **Even assuming zero transmission loss through the airframe, the signal is 15–25 dB below background at any legal safe distance.** The conclusion does not depend on the airframe-loss estimate:

- **Reliable decoding radius ≈ 1 m (calm), 0.3–0.5 m with wind.**
- **After walking away there is no information channel at all.** Everything a person must know has to be heard **as the last step before clearing the pad, within 1 m of the rocket**. Everything that changes after walking away (battery sag, an igniter lead coming loose, a blown fuse, an MCU reset) must be handled autonomously by firmware and logged, **never "beep and hope"**.
- A free remedy: aim one av-bay vent at the buzzer as a sound port (counted in the vent-area budget, away from the MS5611). New failure: one more light path and water path, and the vent area must be recomputed.

Three more hard constraints:
1. The MLT-8530 is a 2.7 kHz resonant electromagnetic buzzer; **off resonance it doesn't change pitch, it loses 15–20 dB**. So §7.14's "high/low tone" coding cannot be implemented on this transducer — **the language can only use durations and counts, at a constant frequency**. Sweep on the bench to find the real resonant peak (already required by §7.14).
2. The buzzer is a 95 mA / 0.31 W load on 3V3, and the LC corner is 12.8 kHz, so **2.7 kHz lands below the corner, essentially unattenuated (about +0.4 dB), on 3V3A = VDDA = VREF+**; it is also a 2.7 kHz mechanical pressure source bolted to the same board, right next to the 800 Hz-sampled IMU and the gel-sealed MS5611. **Rule: the buzzer must be silent during any measurement that feeds a pass/fail criterion** (including H-1's millivolt-level pyro readings, the battery load step, IMU noise floor, and the baro σ / dP/dT measurements — the latter coupling is **acoustic** and strongest in a **sealed bay**, reading "sealed" as "vented", anti-correlated with the truth). For measurement windows longer than 2 s, use the yellow LED as heartbeat and announce the start and end of the silent window with a distinct pattern.
3. Recompute the hold-up budget with the real load: 470 µF's 12 mJ is 18.2 ms at 0.65 W, **only ≈ 12.5 ms with the buzzer's 0.31 W added**, and the pad / ascent is exactly when it is sounding. **The buzzer is silent from launch detection until landing** (nobody can hear it, it wastes a third of the brown-out budget, and it pollutes measurements).

### 6.2 Tone codes

Elements: `·` = 60 ms, `—` = 300 ms, 120 ms between elements, 500 ms between groups. All at the measured resonant frequency.

| State | Pattern | Period |
|---|---|---|
| Proof of life (< 50 ms after reset, **unconditional, before any test**) | `— ·` (this combination appears in no periodic pattern, so a reset loop cannot masquerade as healthy) | Once |
| Self-test in progress | `·` every 150 ms (fast trill) | Continuous |
| SAFE / disarmed / all passed | `—` `[ch1]` `[ch2]`, `·` = igniter present, `—` = open | 2 s |
| Warnings present but armable | SAFE tone, with `— —` + N × `·` inserted every third frame | 2 s |
| REFUSE (not armable) | `— —` + N × `·`, forever. **Never sounds the READY tone** | 2 s |
| Armed but not ready | Same, frame compressed to 1 s (sounds more urgent) | 1 s |
| **ARMED-READY (go)** | `· · ·` — no other three-short pattern exists in the language | 1 s |
| **PYRO HAZARD** | **A continuous unbroken tone** — the only continuous tone in the language, with one meaning: **do not approach, do not insert the ARM plug, pull the ARM plug now** | — |
| In flight | Silent | — |
| Landed locator | `—` every 5 s | 5 s |

**Fault codes (N × `·`)**: 1 battery / 2 supply rail or VREF (including `ANALOG_RAIL_FAULT`) / 3 IMU absent or self-test failed / 4 IMU noise floor abnormal (suspect joint or mounting) / 5 barometer absent or PROM CRC / 6 implausible barometer readings / 7 suspected av-bay seal (vent) / 8 storage / 9 pyro ch1 / 10 pyro ch2 / 11 inconsistent ARM / pull-pin / USB state / 12 servos / 13 GNSS no fix (warning only) / 14 unexplained reset on the last flight.

**LED language (the only channel when someone is wearing ear defenders, or working with the bay open in a noisy prep area)**: red = hazard/refuse states (solid for hazard, fault-code flashes for refuse); yellow = heartbeat, one flash per frame. **Numeric codes are given as red LED flash counts, not beep counts** — counting fourteen 60 ms beeps against a 76 dBA background plus wind is impossible, while an LED is fully readable at the 1 m the READY confirmation requires anyway. The fault-code table is printed on the silkscreen and on a laminated card that travels with the rocket box.

**Three hard rules in the driver layer**: silence is never a healthy state (every state must sound within ≤ 2 s); the continuous tone has exactly one meaning; **one single low-level driver** enforces a ≤ 25 % duty-cycle ceiling outside the hazard state (not for hold-up, but because an always-on buzzer **masks every other code** and, per §6.1 item 2, pollutes every measurement).

### 6.3 Procedures

**Bench (powered, ARM link out, pull-pin inserted)**
- **T-1 load-switch integrity**: battery connected, external switch **OFF**, USB plugged in. `VBAT_SENSE (PC4)` must read **< 0.2 V** (RAW then floats only through R3/R4's 147k, with D2 blocking in reverse). Higher = Q1/Q2 drain-source short, a stuck switch, or the SW wire chafed to ground → no fly. **This is the only test that can find I-6, and it can only be done with the switch OFF and USB power; a pad self-test can never do it.** (It also voids §7.10's "reads ≈ 1.487 V on USB power alone": that number assumes RAW sits at VLOGIC, which D2's direction forbids; the real value is set by SS34 reverse leakage and is **undetermined**, anywhere from millivolts to a volt depending on the part and temperature, so it cannot be a criterion. USB presence is judged **only by PD15**.)
- **T-2 battery load step** (the only test that finds "8.4 V open-circuit but high internal resistance"): step all four servos ±5° together, sample `VBAT_SENSE` at 1 kHz, and compare with that vehicle's golden baseline from build. Ratio > 1.4 = high internal resistance / loose terminal / cold battery → no fly; < 0.6 = a linkage has come off → warning. Limit the amplitude to ±5° about centre and abort immediately if `VBAT < 6.6 V`.
- **T-3 pyro cold self-test** (H-1): ARM out, both gates low, read jointly per the table in §4.1. Any 0 mV or > 100 mV → continuous tone, **do not touch the ARM plug**. Then a 10 ms gate pulse per channel in turn; CONT must collapse to ≈ 0 and recover.
- **T-4 per-wire terminal check** (the only defence against V-16): ARM out, both igniters connected, measure each BUS ↔ OUT on a DMM low-current range; it must read the igniter resistance, **≥ 1.0 Ω** (a rev G hard requirement); near zero = no fly. Record the values on the flight card.
- **T-5 human-in-the-loop sensor checks**: a tap test (for 20 s, chirp once for every > 2 g transient; the operator taps three times and counts three chirps — in one step this proves the IMU is alive, DRDY is firing, the ISR is running, the buzzer works, and **the sensor is mechanically coupled to the airframe**, which no purely electrical test can show); a vent test (for 20 s, chirp once for every |ΔP| > 0.5 hPa; the operator covers and uncovers the vent — **the only reliable vent criterion on a calm day**).
- **T-6 full-travel servo sweep**, visually confirming all four fins move and return to centre; one chirp per commanded position so the observer knows which one is being tested.
- Also on the bench: full-chip erase (**only here**), F-20's storage self-test, GNSS lock confirmation (**warning only, never a go criterion**), remove the DFU jumper from J2 and wrap it in clear heat shrink, unplug the USB cable.

**Assembly**
- Terminate all 4 battery/switch wires and all 6 ARM/PYRO wires **outside the airframe** and torque to 0.4 N·m (rev G §7.3-3: they cannot be tightened inside), using only tinned solid wire or ferrules; pull-test each wire; mark each screw with torque paint.
- Make the charge and igniter a sealed assembly; weigh and record the charge; put a paint mark on the igniter lead where it enters the charge well so movement is visible; photograph every charge well; a second person signs. **No electrical measurement can tell whether an igniter is actually in its charge well.**
- Harness per IREC DTEG Appendix B: strain-relief slack at every termination; the 3×4 servo header must be positively retained by a zip tie through the 3 mm hole (the header itself has no latch); no twisted splices or wire nuts; no tape/glue/RTV as insulation or bundling; only clear heat shrink so terminations stay visible; **stake every part > 7 g** (on this board: the two 10 mm 470 µF cans, the two 14 mm screw terminals and the buzzer; L1/L2 are also recommended, with a visual and resistance check); the battery must be rigidly held in a fixture, never by hook-and-loop or zip ties alone.
- Insert the pull-pin and confirm the board reads "inserted" (which also proves the pull-pin wire is intact). Close the airframe. **Confirm the 3–4 vents are open and untaped.**

**On the pad**
1. Rocket on the rail, vertical.
2. **Power this board first (ARM link still out)**: hear the proof-of-life tone → self-test trill → SAFE tone, and decode the two continuity symbols. **This ordering is the general means of downgrading the whole class of "only shows up at power-up" ① events — I-1 / I-5 / I-6 / V-14 — into bench / early-pad findings. Silence = no fly.**
3. Arm the **backup altimeter** and confirm its own continuity tones.
4. **Insert this board's ARM link last** (it is the electrical safety device). Within 2 s the tone must change from SAFE to ARMED; also check the ratio `ARM_SENSE / (VBAT_SENSE × 147/47) = 1/11 ± 15 %` (computed with the VREFINT-calibrated VDDA; **never an absolute millivolt window**: `PC0 = PYRO_BUS / 11`, a 6.4 V battery gives 0.582 V, and an absolute window would flag a battery state §7 explicitly allows as a fault).
5. Pull the pull-pin and hear the state change.
6. At ≤ 1 m confirm the `· · ·` READY tone and clear the pad. **Know clearly that this is the last piece of information you will get.**
7. Before launch, any unexpected boot tone → abort, return to the rocket, pull the ARM link first.

**Recovery**
8. Approach from the side, **never standing in line with any charge well or directly in front of the nose**.
9. **Pull this board's ARM link first** and confirm the armed tone stops; then switch off the backup altimeter; finally switch off main power and touch the airframe.
10. After landing, read the log before powering the board for any other purpose. **Any reset between launch detection and landing grounds that vehicle.**

---

## 7. Real-world failure frequency vs where we spend

### 7.1 What the rules require (primary text)

- **NAR High Power Rocket Safety Code** (the PDF nar.org serves today, self-labelled "Revision of August 2012") only requires "I will use a recovery system such as a parachute…", plus two lines that bind this design: "**The function of onboard energetics and firing circuits will be inhibited except when my rocket is in the launching position**" and "When arming onboard energetics and firing circuits I will ensure that no person is at the pad except safety personnel and those required for arming and disarming operations."
- **Tripoli Unified Safety Code v2 (effective January 2026)**: 11-1 landing speed ≤ 35 ft/s; **11-6** total impulse > 2560 N·s requires an "electronically controlled recovery system which does not rely upon the motor"; **13-8** electronic recovery devices stay inhibited until the rocket is erected in position and before the igniter is installed; 13-10 disarm before lowering. **"redundan" appears zero times in the whole text.**
- **Redundancy is mandated in only two places, both defined the same way**: Tripoli L3 certification requires "Dual redundant electronics… two completely independent and separate electronic recovery systems… redundancy means completely separate systems, including batteries, switches, avionics, and energetics"; IREC / Spaceport America Cup DTEG 2026 §6.9.1 has the same list, §6.9.2 says "A dual pole switch does not satisfy the requirement for redundant arming switches", §6.10.1 requires at least one of the two to be COTS, and §6.11.3 says "A COTS microcontroller running SRAD flight software shall be considered an SRAD system" — **this board can never serve as the COTS half**.

**Compliance conclusion**: this design is **compliant** for ordinary L1/L2 club flights, because the removable fused ARM link is a real physical break on `PYRO_BUS`, satisfying "inhibited except in the launching position" — **provided the ground procedure really does insert it last and pull it before lowering**, and V-18 shows that premise does not hold with the current mechanical design. It **does not meet** the L3 / IREC definition of redundancy, and the two on-board pyro channels are far from that definition.

(One difference rather than a violation: IREC DTEG §6.17.1.1 forbids LiPo inside the rocket; NAR and Tripoli do not. This rocket's 2S LiPo is legal at club launches but, as is, cannot fly at IREC.)

### 7.2 What shipping products actually do (primary documents)

- **AltOS 1.9.22 source** (Debian orig tarball, grep of the whole tree): **no watchdog on any flight-computer product** — `ao_watchdog.c` is only built for `src/fox1ihu` (a CubeSat IHU), and it kicks an external chip via GPIO rather than using an IWDG. TeleMetrum / TeleMega / EasyMini ship **deliberately** without a watchdog. There is also no cross-reset persistence of flight state: `ao_flight()` always starts from `ao_flight_startup` and re-decides pad/idle/invalid. **An in-air reset also loses the flight on AltOS — but it never resets itself, and never permanently disarms.**
- **Featherweight Blue Raven user manual (2026-05-12 edition)**: "Manual arm… When false (**default for deployments**), the channel is **enabled at power up**." Deployment channels are armed at power-up; safety comes from elsewhere — a vehicle-level event "**Liftoff Detected — Always required before any deployment**", plus the hardware interlock described on the product page, "disables all outputs when the microcontroller voltage is below 2.7V, including start-up, shutdown, and brown-out situations". Apogee uses a **2-of-3 vote**: "fires when 2 of 3 independent sensor methods detect apogee… barometric pressure increasing, gyro-based flight tilt exceeding 90 degrees, and accel-only velocity estimate of less than 0 feet/second", with a transonic lockout (`Vel1 < 400 ft/s`), an apogee latch, an "Apo channel fired + 1.5 s" gate, and a descent-rate backup main (`Bvel1 < −200 ft/s`, "Early main deployment if apogee charge fails and rocket is falling too fast"). The manual also addresses the sealed-bay case explicitly: "The default deployment settings of the Blue Raven will work based on gyro and accelerometer measurements for apogee deployments **even if the av-bay is sealed**" — a shipping product with a large flight history **designed inertial votes specifically for blocked vents**, which is why §7.7's absolute prohibition must become conditional.
- **PerfectFlite StratoLoggerCF**: designed **not to reset** — "can tolerate a power loss of several seconds (depending on battery voltage) without resetting", with dedicated power-up error codes 1 "Total power loss during last flight" and 2 "Momentary power loss during last flight… brownout protection allowed the altimeter to continue normal operation, but a loose connection or other issue is likely". *(This quote comes from a fetch in another domain; perfectflite.com's TLS certificate has expired and it could not be re-checked this round — **treat as unverified**.)*
- **Eggtimer Quantum (user guide 1.09G)**: "The Quantum is designed so that it will not self-arm itself" (a person must enter a check code); its recommended L3 wiring uses a **separate** deployment battery because "having the separate deployment battery 100% prevents any kind of deployment glitch from affecting the flight computer side"; the rationale for its FailSafe feature reads: "Almost everyone who's had enough electronic-deployment flights has had a flight end badly because of a drogue deployment failure. Some common failures are: motor eject charge fires late, or doesn't fire at all; drogue gets stuck in the body tube; shorted or bad ematch doesn't fire."
- **AltusMetrum manual**: "Apogee lockout is the number of seconds after launch where the flight computer will not fire the apogee charge, even if the rocket appears to be at apogee. This is often called Mach Delay…" — **the timer is an inhibit, not a trigger**; the same page explains transonic handling is done with a Kalman filter rather than an accelerometer AND gate, and recommends leaving this default at zero.

**The fleet's answer is consistent, and it is the opposite of frozen §7's**: nobody resets because a sensor stalls; either there is no watchdog at all or the design rides through disturbances; nobody permanently disarms in flight; everyone gates firing on a latched lift-off detection. **The §7.1 + §7.4 combination (only feed point = the IMU ISR, and no re-arm after reset) is worse than every shipping product I could find: it turns a survivable sensor hiccup into a guaranteed ballistic rocket.**

### 7.3 What actually destroys amateur rockets, and whether our spending is in the right place

There are no rigorous public statistics (this must be stated honestly). Three kinds of indirect evidence are available, and all point the same way: which faults vendors designed dedicated error codes and features for (of the StratoLoggerCF's six power-up error codes, **two** are for power interruption and **zero** for sensor algorithms); where vendors spend the words in their manuals (switch bounce, terminal wire retention and connector seating far outweigh decision logic); and IREC DTEG Appendix B — **almost entirely mechanical clauses**: strain relief at every termination, positive locking of every mated pair, no twisted splices or wire nuts, no tape/glue/RTV, a pull test on every termination, "All components greater than 7g shall be staked", "'Velcro' and/or tie wraps shall not be used as the sole method of mounting batteries".

**So this rocket's redundancy budget, in order:**

1. **A permanently fitted independent commercial altimeter** (own battery / switch / igniter / charge) + **a permanently fitted independent GPS tracker**. The only thing that covers V-4, V-10 and firmware defects; zero changes to this board; the cost is a vehicle-level geometry decision (§3.2).
2. **All the firmware rules in §2 and §5. Zero parts, the widest coverage.**
3. **Harness, staking, terminal discipline, vent workmanship, ground ejection tests, per-wire DMM checks. Zero parts, covering the class that statistically happens most.**
4. **The 6 parts in §4.1.** They buy three things firmware cannot: a cold pyro self-test, a gate a solder bridge cannot fire, and a readable USB state.
5. Everything else.

**Plainly: a correctly written arming procedure and correctly made strain relief beat any clever electronic redundancy.** The two heaviest musts in this document (a permanent backup altimeter, and taking the watchdog off the IMU) are one procedure and one firmware change; all 6 new parts together are worth less than the single ordering rule "connect the ARM link only after the power-up self-test passes". Conversely, a checklist too long for anyone to follow is worse than a short one — **the pad section (steps 4–6) must fit in five lines, laminated, travelling with the rocket, read back by a second person.**

---

## 8. Net impact and remaining risk

### 8.1 Additions

| Item | Delta |
|---|---|
| Soldered parts | **+6** (47k × 2, BAT54A × 1, 10k × 2, 100k × 1) → 101 → **107 (+5.9 %)**; +11 if H-8/H-9/H-10 are adopted |
| Part numbers | **+1** (BAT54A) → 39 → **40 (+2.6 %)**; the BAT54 family also serves H-10 |
| Area | About 15 mm², all 0402/0603/SOT-23, in the y 34–46 zone, **never in rev G §4's Z2** |
| GPIO | Net +3 (5 sentinels, 2 signals moved) |
| Timers | +1 basic timer (TIM6/TIM7) for the SAFETY task; TIM2 still reserved per §7.3 as the free-running microsecond timebase |
| Netlist changes | J-ARM pin-definition ruling (V-17); optional PYRO_BUS split (H-5); `J1.4` from SW to GND (giving the 12 A return two screw positions, while the 76 µA switch needs only one); `R2` 10k → 1k |
| Firmware | A rework of about 2000–3000 lines + a full set of injection tests (on a shaker, in a pressure pot, injecting resets in every flight phase and verifying the record reads back with a valid CRC and a monotonic sequence). **The largest cost of all, far larger than the parts** |
| Vehicle | Backup altimeter + tracker + their batteries/switches/charge wells → **a longer coupler or a separate bay section** (rev G's +1.558 mm margin cannot absorb it) |
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

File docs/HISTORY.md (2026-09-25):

# Design history

A short record of decisions that were made and later reversed, so they are not re-litigated.

## 1. Single board → two boards → single board

- **REV-G (2026-09-03)**: one 46 × 120 mm four-layer board (`GEOMETRY_REV_G.md`).
- **REV-H/M (2026-09-04)**: split into M1 (power + actuators, 46 × 50–66 mm) and M2 (MCU + sensors, 46 × 96 mm) joined by two JST PH harnesses (S12B-PH / S9B-PH, 21 wires). The argument was cost distribution: ~80 % of the BOM value (GNSS, MCU, IMU, barometer) sat on M2, while every open connector defect sat on the cheap power board, so power-board respins would be cheap.
- **M3 (2026-09-07 onward)**: the split was **reversed** — M1 and M2 are merged back into one board. Reasons: one assembly order instead of two (the fixed JLCPCB setup / stencil / feeder costs are paid once), no 21-contact inter-board harness, no hot-plug rule, and a shorter avionics bay (one board instead of 50 + 18 + 96 mm). The cost accepted: every respin now carries the full set of expensive silicon, and destructive power tests can no longer be done on a cheap sacrificial board.

The legacy M1 power/actuator design lives in `../reference/m1_power_actuator/` because its pyro, arming, servo, pull-pin and buzzer circuits still have to be merged into M3.

## 2. Rules from REV-H/M that still apply

- **M3 tie rods only clamp the bulkheads/sled and never pass through a PCB.** The board is fixed to the sled with its own M3 screws. (REV-G §7.4 had the rods pass through holes 112 mm apart in the plane of the board, which is geometrically impossible for a straight rod.) Hole positions are still open pending the sled design.
- **Connectors are not structural elements** (IREC DTEG 2026 V1.1 §6.12.3.2–6.12.3.3). Any harness connector needs an external retention means: one zip tie over the housing and a second anchoring the harness to the sled ~30 mm downstream. JST does not publish mating/retention force for PH, so the tie is the only defensible retention.
- **Separation targets on the MCU side**: buck switching loop ≥ 30 mm from the IMU; 25 MHz crystal ≥ 40 mm from the GNSS antenna (25 MHz × 63 = 1575.000 MHz, 420 kHz from L1 centre).
- **No switched high current across any boundary**: the 7.66 A servo bus and the 4.0–9.84 A pyro pulses stay in one compact corner.
- **Board placement is coplanar on the sled**: the envelope `h(x) = √(719.8489 − (x − 23)²) − 1.263` from `GEOMETRY_REV_G.md` is unchanged; the binding item is still the plugged servo header (23.50 mm needed, 1.558 mm margin).

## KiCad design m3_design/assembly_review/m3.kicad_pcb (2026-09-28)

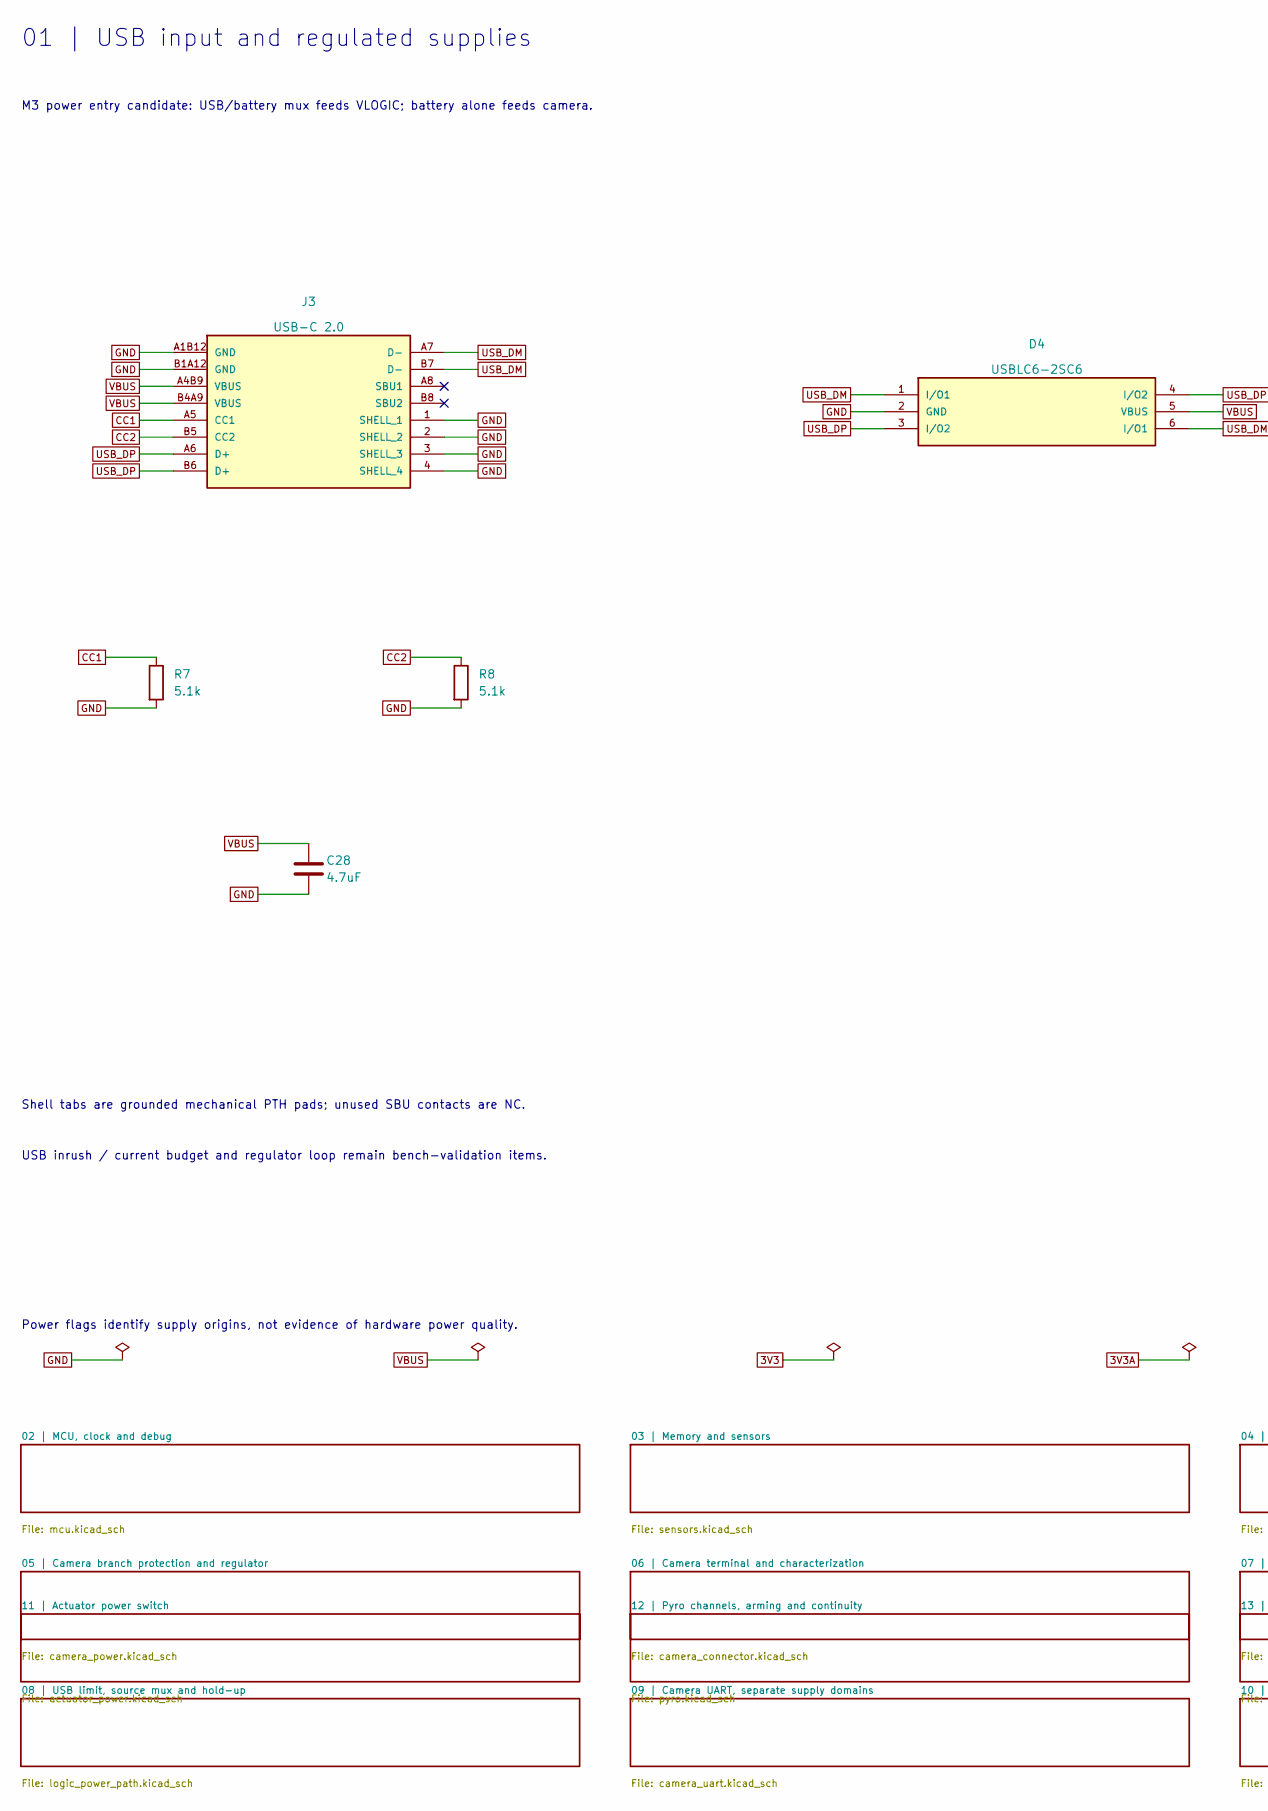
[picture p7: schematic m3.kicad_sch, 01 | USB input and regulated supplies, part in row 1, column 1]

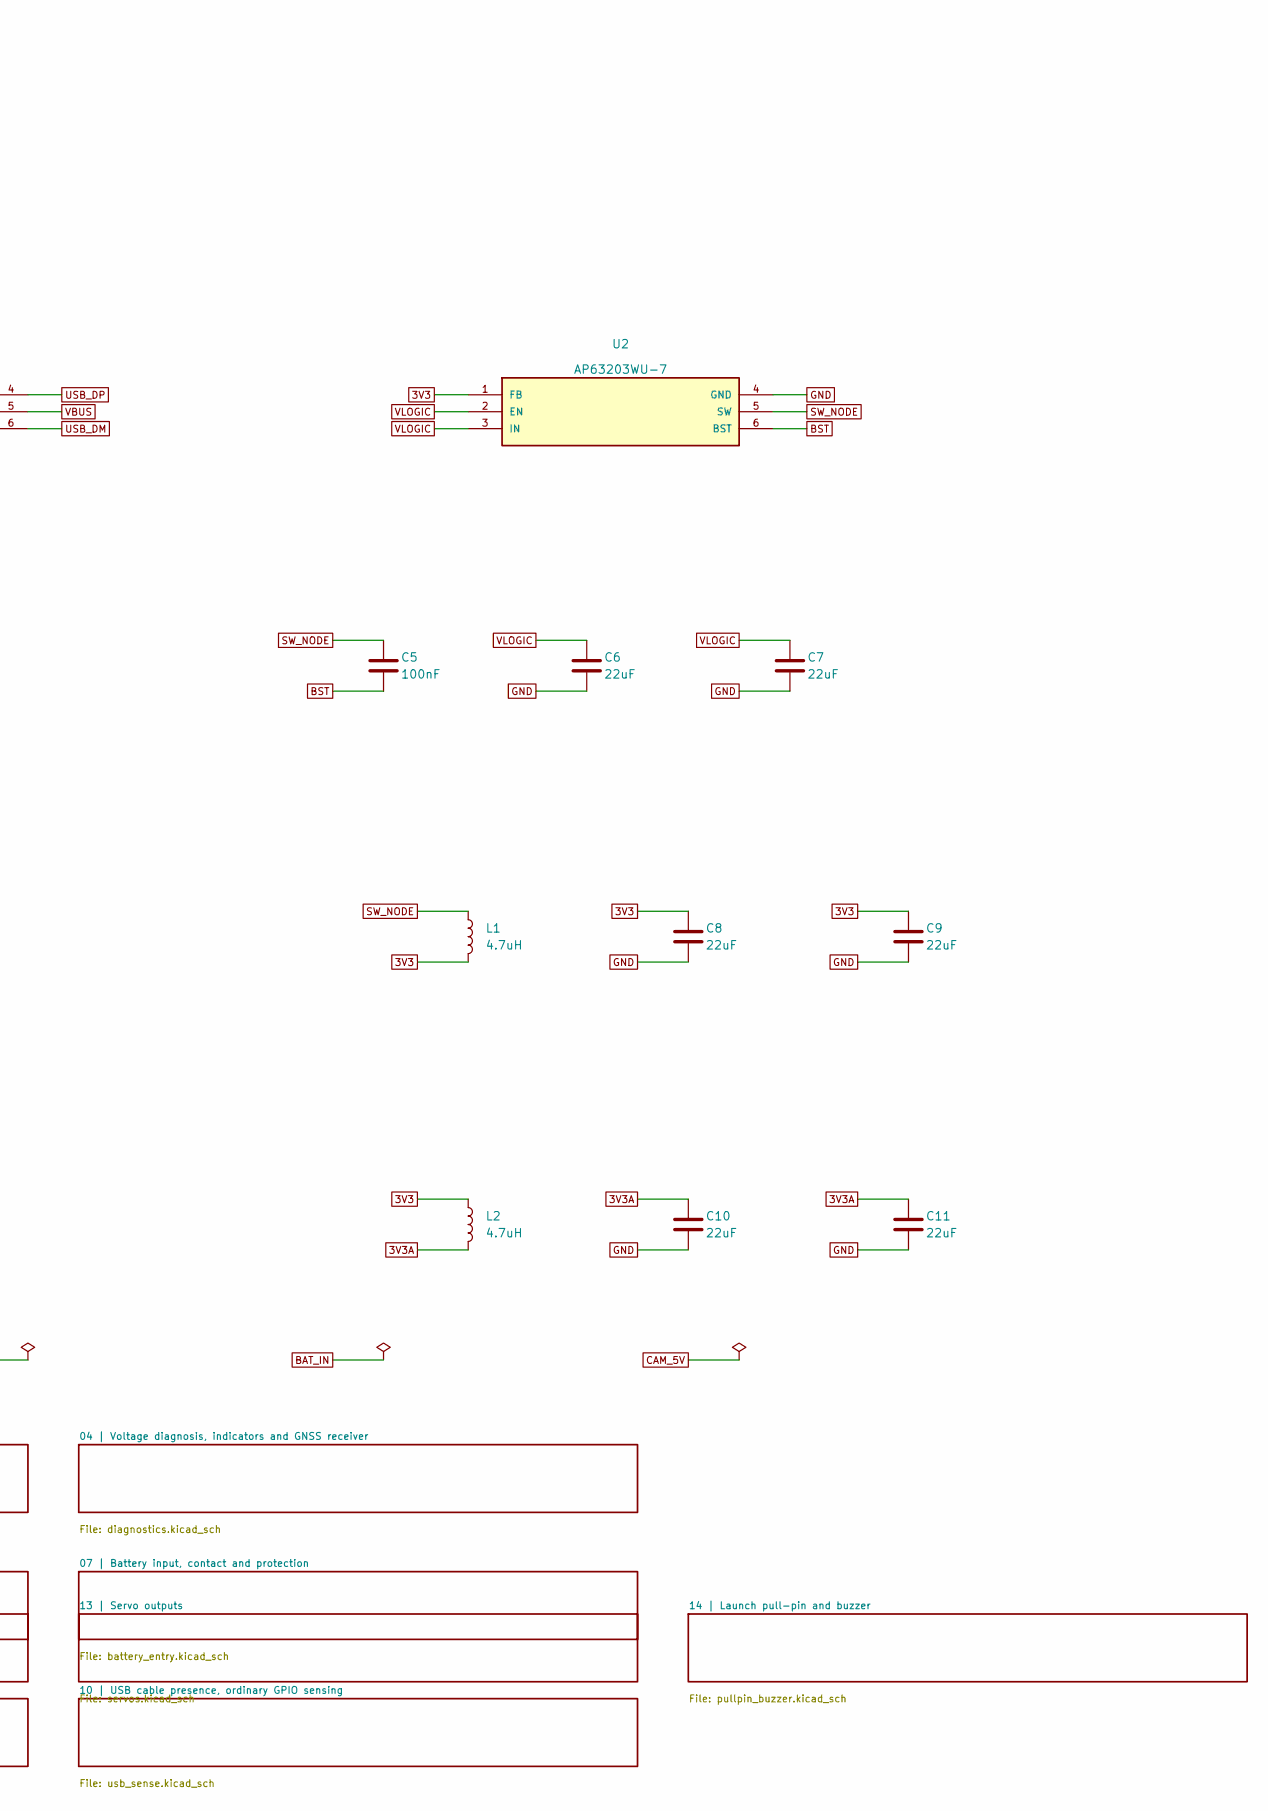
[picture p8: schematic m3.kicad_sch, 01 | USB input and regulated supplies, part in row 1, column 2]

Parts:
C5: 100nF; C0402; LCSC C1525
C6, C7, C8, C9, C10, C11: 22uF; C0805; LCSC C45783
C28: 4.7uF; C0603; LCSC C19666
D4: USBLC6-2SC6; SOT-23-6_L2.9-W1.6-P0.95-LS2.8-BL; LCSC C7519
J3: USB-C 2.0; USB-C_SMD-TYPE-C-31-M-12_1; LCSC C165948
L1, L2: 4.7uH; IND-SMD_L4.0-W4.0; LCSC C57269
R7, R8: 5.1k; R0402; LCSC C25905
U2: AP63203WU-7; TSOT-26_L2.9-W1.6-P0.95-LS2.8-BL; LCSC C780769

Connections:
3V3: C8.1, C9.1, L1.2, L2.1, U2.1 (FB); also elsewhere on the board
3V3A: C10.1, C11.1, L2.2; also elsewhere on the board
BST: C5.2, U2.6 (BST)
CC1: J3.A5 (CC1), R7.1
CC2: J3.B5 (CC2), R8.1
GND: C6.2, C7.2, C8.2, C9.2, C10.2, C11.2, C28.2, D4.2 (GND), J3.1 (SHELL_1), J3.2 (SHELL_2), J3.3 (SHELL_3), J3.4 (SHELL_4), J3.A1B12 (GND), J3.B1A12 (GND), R7.2, R8.2, U2.4 (GND); also elsewhere on the board
SW_NODE: C5.1, L1.1, U2.5 (SW)
USB_DM: D4.1 (I/O1), D4.6 (I/O1), J3.A7 (D-), J3.B7 (D-); also elsewhere on the board
USB_DP: D4.3 (I/O2), D4.4 (I/O2), J3.A6 (D+), J3.B6 (D+); also elsewhere on the board
VBUS: C28.1, D4.5 (VBUS), J3.A4B9 (VBUS), J3.B4A9 (VBUS); also elsewhere on the board
VLOGIC: C6.1, C7.1, U2.2 (EN), U2.3 (IN); also elsewhere on the board

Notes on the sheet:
01 | USB input and regulated supplies
M3 power entry candidate: USB/battery mux feeds VLOGIC; battery alone feeds camera.
Shell tabs are grounded mechanical PTH pads; unused SBU contacts are NC.
USB inrush / current budget and regulator loop remain bench-validation items.
Power flags identify supply origins, not evidence of hardware power quality.

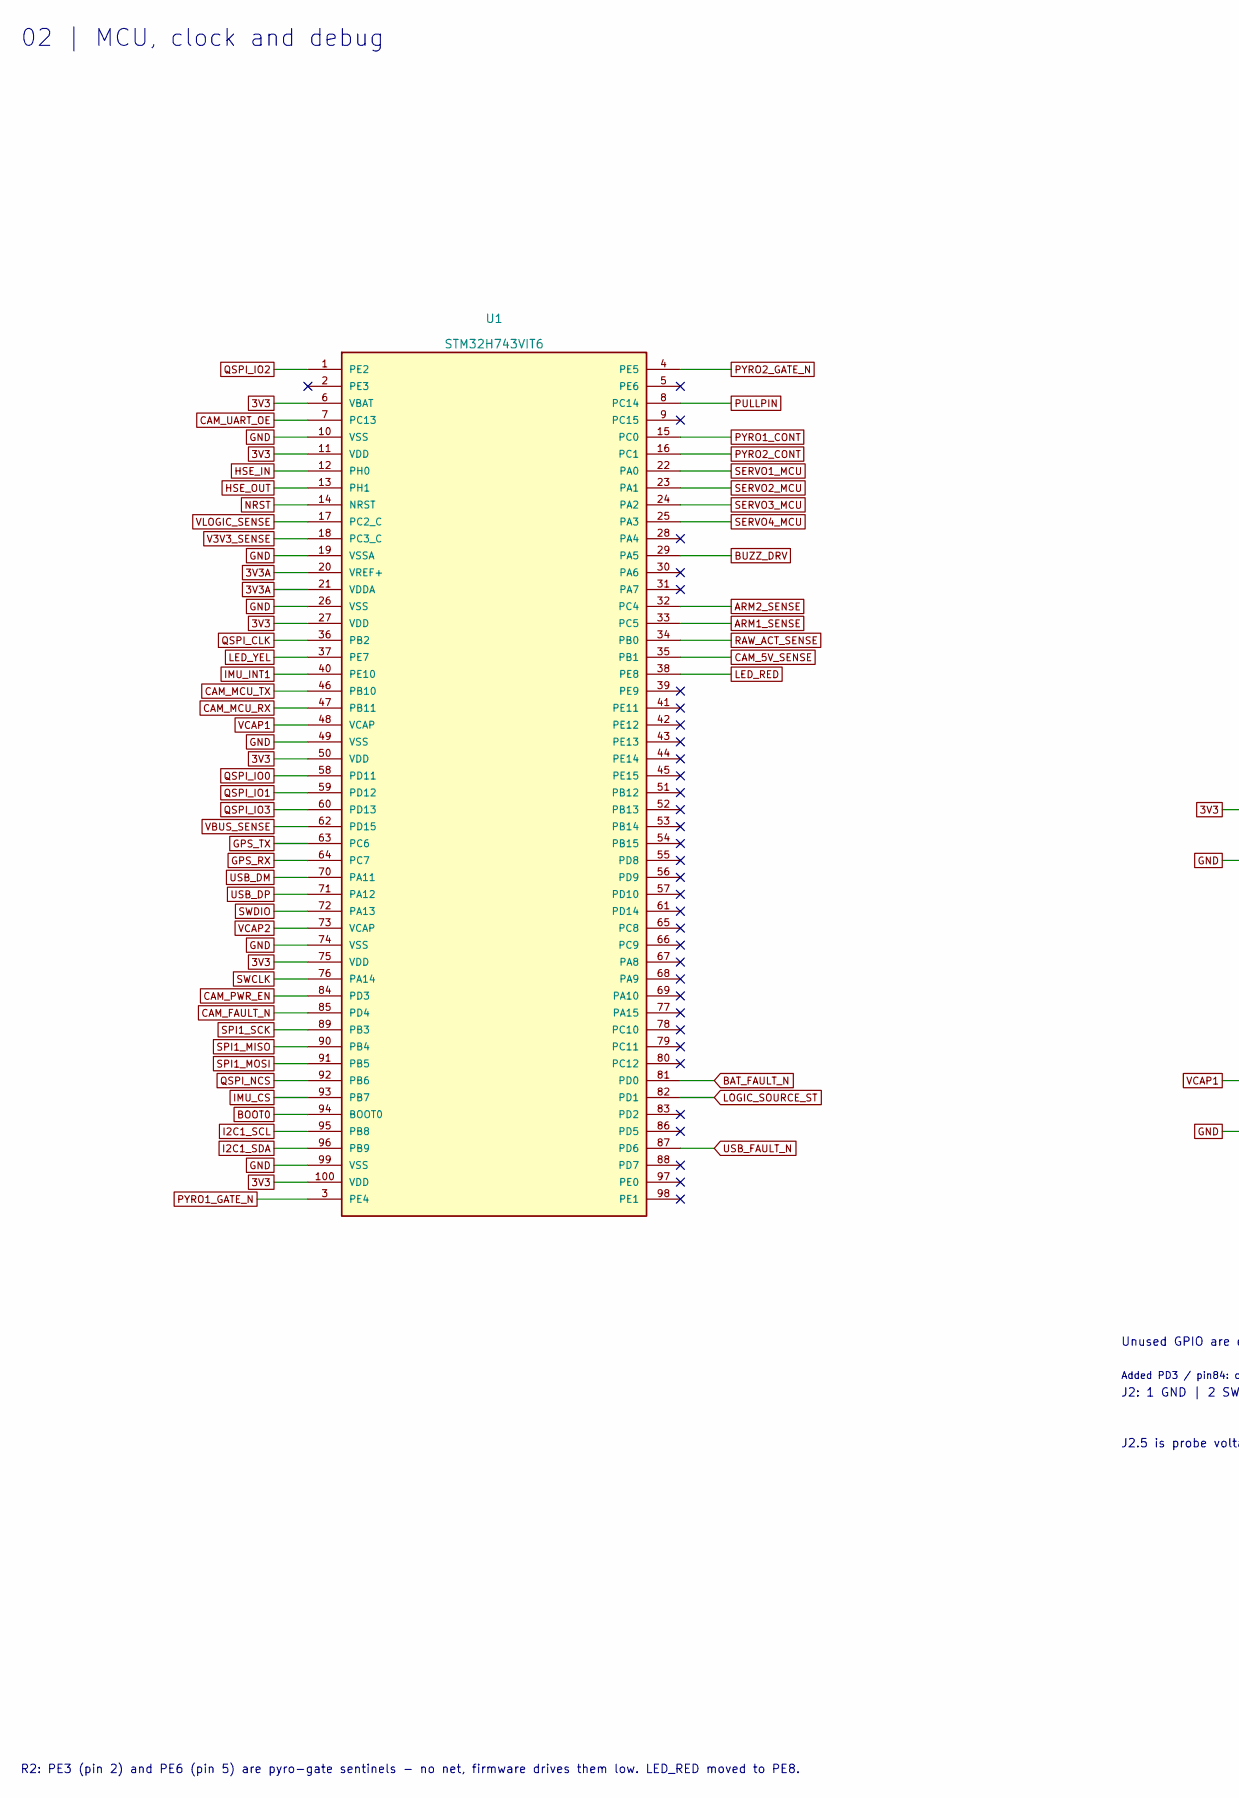
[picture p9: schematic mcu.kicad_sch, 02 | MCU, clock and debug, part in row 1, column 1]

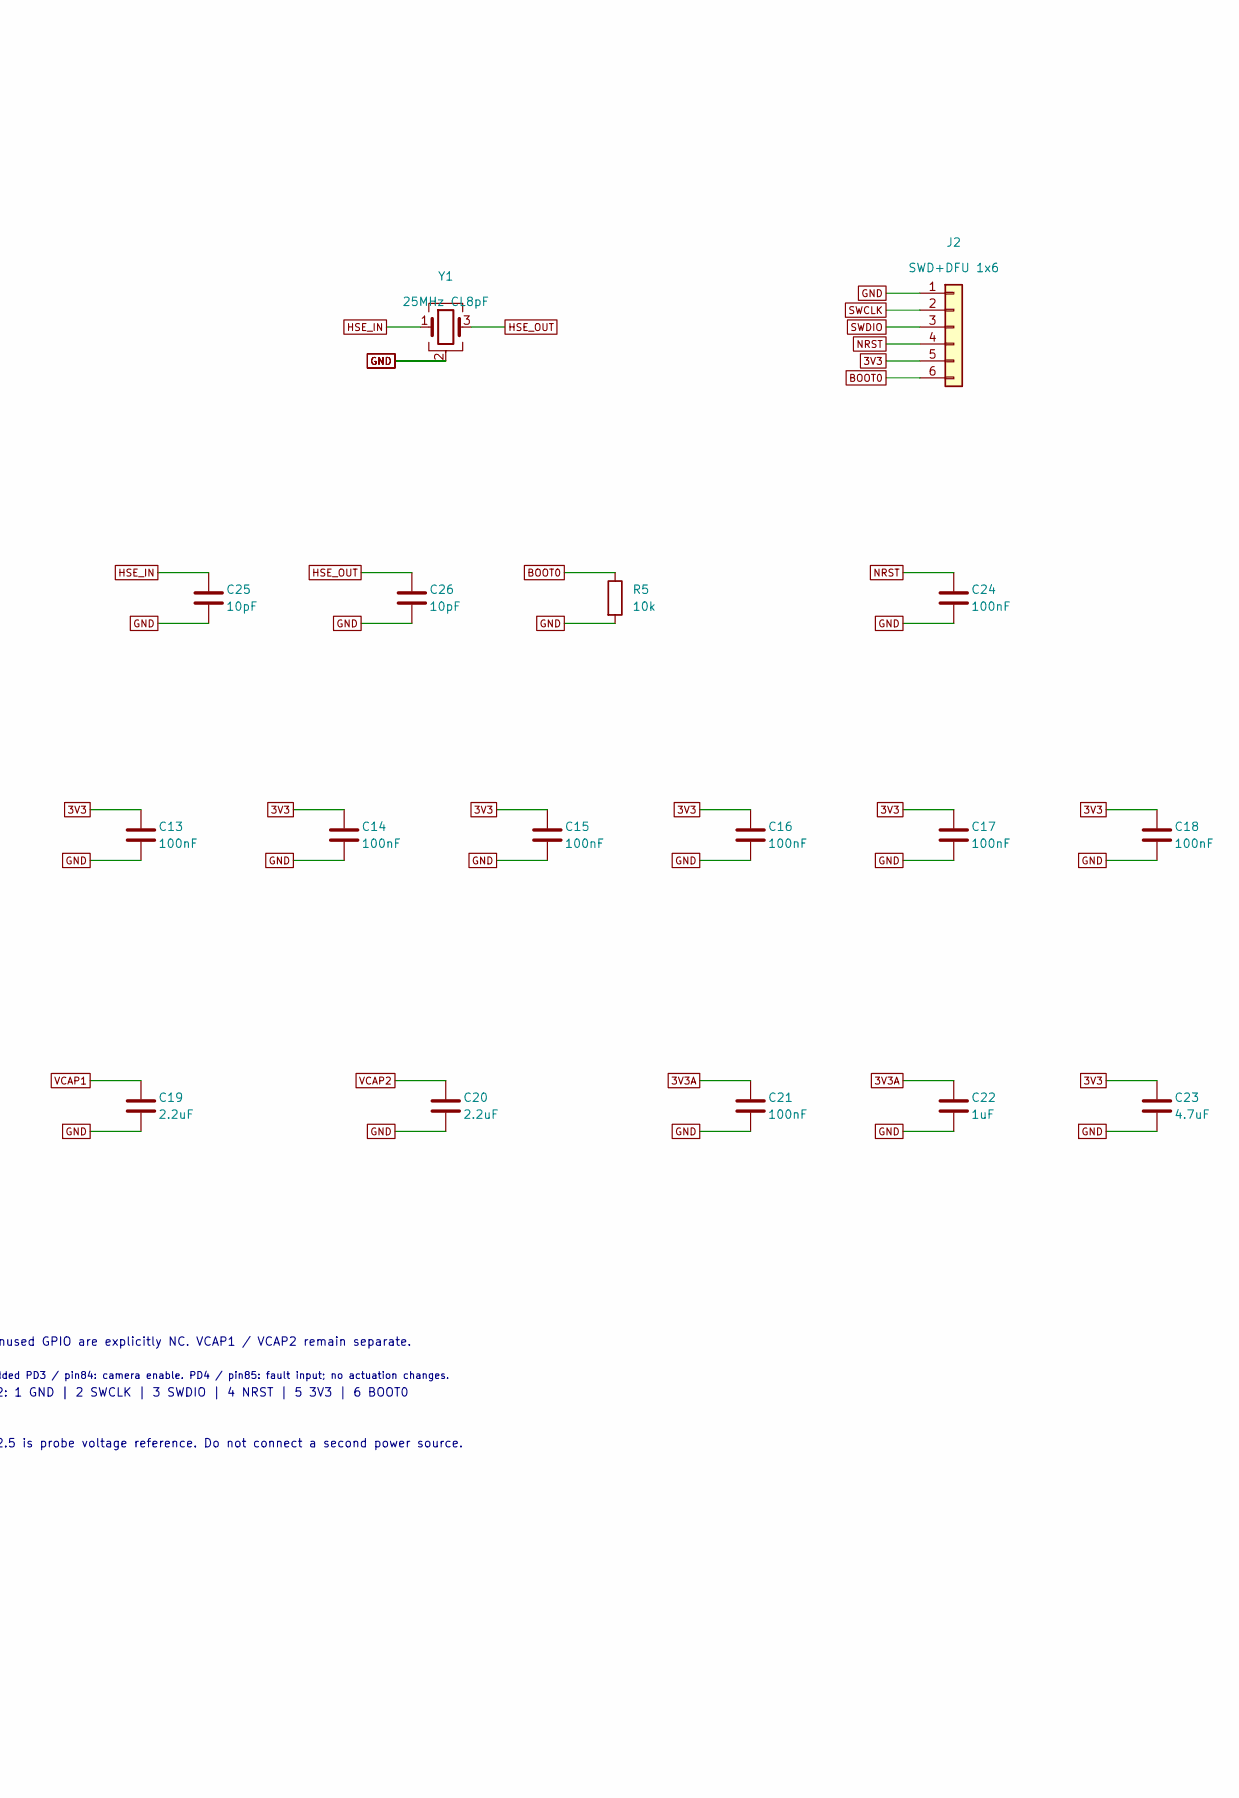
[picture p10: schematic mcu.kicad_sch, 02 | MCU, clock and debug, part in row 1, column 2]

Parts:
C13, C14, C15, C16, C17, C18, C21, C24: 100nF; C0402; LCSC C1525
C19, C20: 2.2uF; C0603; LCSC C23630
C22: 1uF; C0603; LCSC C15849
C23: 4.7uF; C0603; LCSC C19666
C25, C26: 10pF; C0402; LCSC C32949
J2: SWD+DFU 1x6; HDR-TH_6P-P2.54-V-M-1x6; Manufacturer Part PZ254V-11-06P; LCSC C492405
R5: 10k; R0402; LCSC C25744
U1: STM32H743VIT6; LQFP-100_L14.0-W14.0-P0.50-LS16.0-BL; LCSC C5271084
Y1: 25MHz CL8pF; CRYSTAL-SMD_4P-L3.2-W2.5-BL; LCSC C1985619

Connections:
3V3: C13.1, C14.1, C15.1, C16.1, C17.1, C18.1, C23.1, J2.5, U1.6 (VBAT), U1.11 (VDD), U1.27 (VDD), U1.50 (VDD), U1.75 (VDD), U1.100 (VDD); also elsewhere on the board
3V3A: C21.1, C22.1, U1.20 (VREF+), U1.21 (VDDA); also elsewhere on the board
ARM1_SENSE: U1.33 (PC5); also elsewhere on the board
ARM2_SENSE: U1.32 (PC4); also elsewhere on the board
BAT_FAULT_N: U1.81 (PD0); also elsewhere on the board
BOOT0: J2.6, R5.1, U1.94 (BOOT0)
BUZZ_DRV: U1.29 (PA5); also elsewhere on the board
CAM_5V_SENSE: U1.35 (PB1); also elsewhere on the board
CAM_FAULT_N: U1.85 (PD4); also elsewhere on the board
CAM_MCU_RX: U1.47 (PB11); also elsewhere on the board
CAM_MCU_TX: U1.46 (PB10); also elsewhere on the board
CAM_PWR_EN: U1.84 (PD3); also elsewhere on the board
CAM_UART_OE: U1.7 (PC13); also elsewhere on the board
GND: C13.2, C14.2, C15.2, C16.2, C17.2, C18.2, C19.2, C20.2, C21.2, C22.2, C23.2, C24.2, C25.2, C26.2, J2.1, R5.2, U1.10 (VSS), U1.19 (VSSA), U1.26 (VSS), U1.49 (VSS), U1.74 (VSS), U1.99 (VSS), Y1.2 (G), Y1.4 (G); also elsewhere on the board
GPS_RX: U1.64 (PC7); also elsewhere on the board
GPS_TX: U1.63 (PC6); also elsewhere on the board
HSE_IN: C25.1, U1.12 (PH0), Y1.1
HSE_OUT: C26.1, U1.13 (PH1), Y1.3
I2C1_SCL: U1.95 (PB8); also elsewhere on the board
I2C1_SDA: U1.96 (PB9); also elsewhere on the board
IMU_CS: U1.93 (PB7); also elsewhere on the board
IMU_INT1: U1.40 (PE10); also elsewhere on the board
LED_RED: U1.38 (PE8); also elsewhere on the board
LED_YEL: U1.37 (PE7); also elsewhere on the board
LOGIC_SOURCE_ST: U1.82 (PD1); also elsewhere on the board
NRST: C24.1, J2.4, U1.14 (NRST)
PULLPIN: U1.8 (PC14); also elsewhere on the board
PYRO1_CONT: U1.15 (PC0); also elsewhere on the board
PYRO1_GATE_N: U1.3 (PE4); also elsewhere on the board
PYRO2_CONT: U1.16 (PC1); also elsewhere on the board
PYRO2_GATE_N: U1.4 (PE5); also elsewhere on the board
QSPI_CLK: U1.36 (PB2); also elsewhere on the board
QSPI_IO0: U1.58 (PD11); also elsewhere on the board
QSPI_IO1: U1.59 (PD12); also elsewhere on the board
QSPI_IO2: U1.1 (PE2); also elsewhere on the board
QSPI_IO3: U1.60 (PD13); also elsewhere on the board
QSPI_NCS: U1.92 (PB6); also elsewhere on the board
RAW_ACT_SENSE: U1.34 (PB0); also elsewhere on the board
SERVO1_MCU: U1.22 (PA0); also elsewhere on the board
SERVO2_MCU: U1.23 (PA1); also elsewhere on the board
SERVO3_MCU: U1.24 (PA2); also elsewhere on the board
SERVO4_MCU: U1.25 (PA3); also elsewhere on the board
SPI1_MISO: U1.90 (PB4); also elsewhere on the board
SPI1_MOSI: U1.91 (PB5); also elsewhere on the board
SPI1_SCK: U1.89 (PB3); also elsewhere on the board
SWCLK: J2.2, U1.76 (PA14)
SWDIO: J2.3, U1.72 (PA13)
USB_DM: U1.70 (PA11); also elsewhere on the board
USB_DP: U1.71 (PA12); also elsewhere on the board
USB_FAULT_N: U1.87 (PD6); also elsewhere on the board
V3V3_SENSE: U1.18 (PC3_C); also elsewhere on the board
VBUS_SENSE: U1.62 (PD15); also elsewhere on the board
VCAP1: C19.1, U1.48 (VCAP)
VCAP2: C20.1, U1.73 (VCAP)
VLOGIC_SENSE: U1.17 (PC2_C); also elsewhere on the board

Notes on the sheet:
02 | MCU, clock and debug
Added PD3 / pin84: camera enable. PD4 / pin85: fault input; no actuation changes.
Unused GPIO are explicitly NC. VCAP1 / VCAP2 remain separate.
J2: 1 GND | 2 SWCLK | 3 SWDIO | 4 NRST | 5 3V3 | 6 BOOT0
J2.5 is probe voltage reference. Do not connect a second power source.
R2: PE3 (pin 2) and PE6 (pin 5) are pyro-gate sentinels - no net, firmware drives them low. LED_RED moved to PE8.

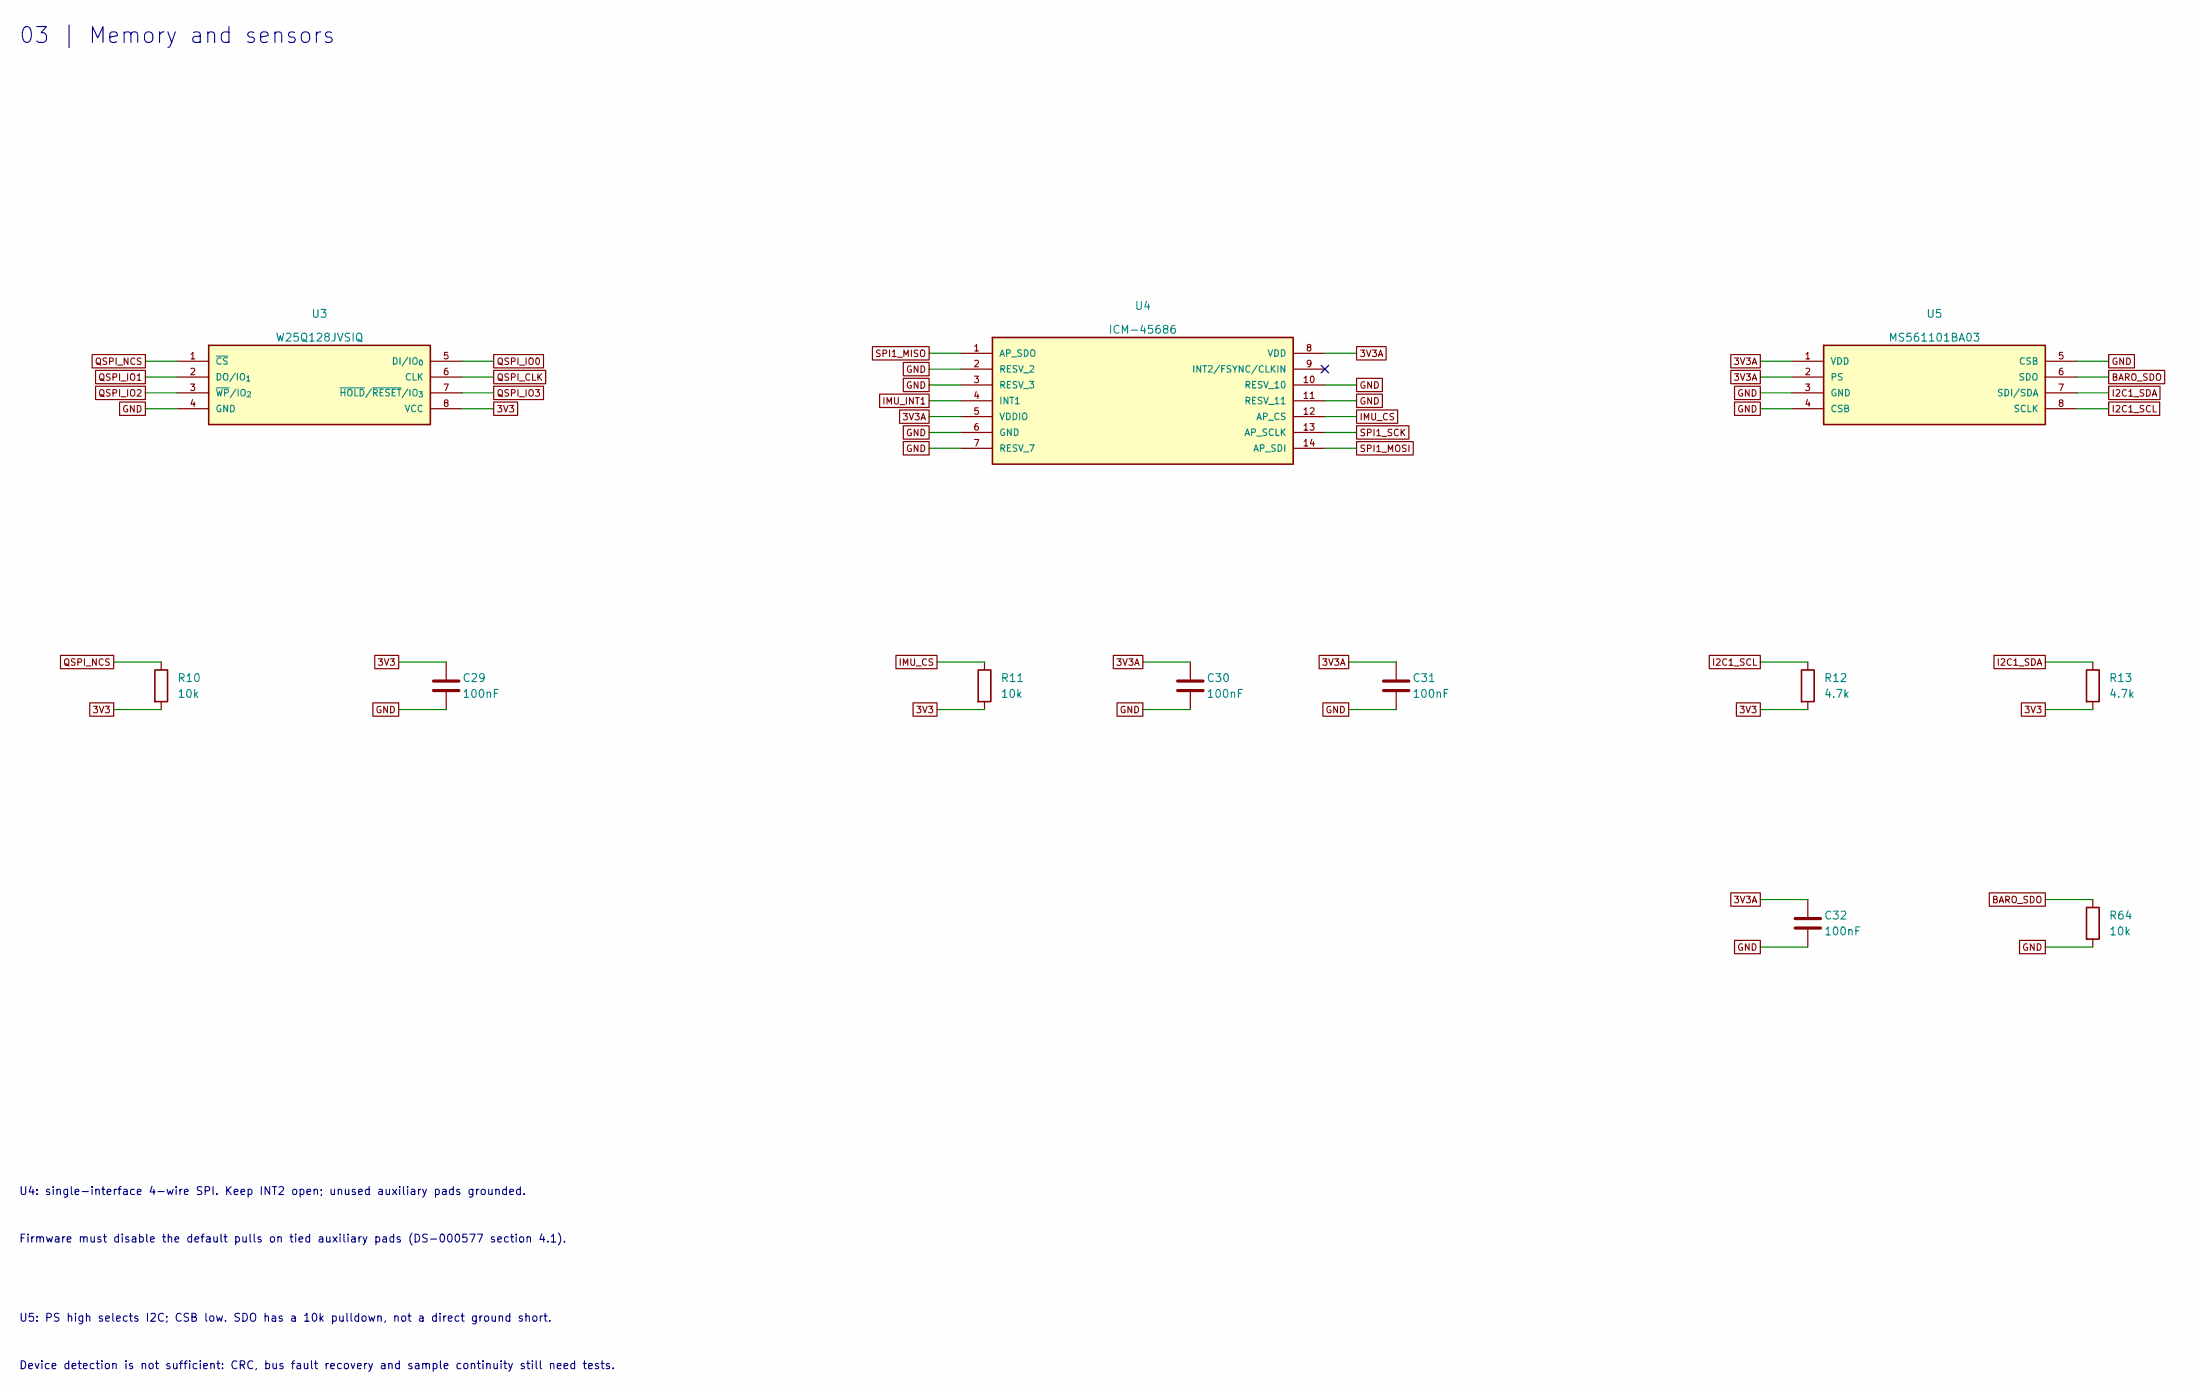
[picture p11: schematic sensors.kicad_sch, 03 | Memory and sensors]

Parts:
C29, C30, C31, C32: 100nF; C0402; LCSC C1525
R10, R11, R64: 10k; R0402; LCSC C25744
R12, R13: 4.7k; R0402; LCSC C25900
U3: W25Q128JVSIQ; SOIC-8_L5.3-W5.3-P1.27-LS8.0-BL; Manufacturer Part W25Q128JVSIQ; LCSC C97521
U4: ICM-45686; LGA-14_L3.0-W2.5-P0.50-TL; LCSC C22459454
U5: MS561101BA03; SENSORS-SMD_MS5611-01BA03; LCSC C15639

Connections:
3V3: C29.1, R10.2, R11.2, R12.2, R13.2, U3.8 (VCC); also elsewhere on the board
3V3A: C30.1, C31.1, C32.1, U4.5 (VDDIO), U4.8 (VDD), U5.1 (VDD), U5.2 (PS); also elsewhere on the board
BARO_SDO: R64.1, U5.6 (SDO)
GND: C29.2, C30.2, C31.2, C32.2, R64.2, U3.4 (GND), U4.2 (RESV_2), U4.3 (RESV_3), U4.6 (GND), U4.7 (RESV_7), U4.10 (RESV_10), U4.11 (RESV_11), U5.3 (GND), U5.4 (CSB), U5.5 (CSB); also elsewhere on the board
I2C1_SCL: R12.1, U5.8 (SCLK); also elsewhere on the board
I2C1_SDA: R13.1, U5.7 (SDI/SDA); also elsewhere on the board
IMU_CS: R11.1, U4.12 (AP_CS); also elsewhere on the board
IMU_INT1: U4.4 (INT1); also elsewhere on the board
QSPI_CLK: U3.6 (CLK); also elsewhere on the board
QSPI_IO0: U3.5 (DI/IO_{0}); also elsewhere on the board
QSPI_IO1: U3.2 (DO/IO_{1}); also elsewhere on the board
QSPI_IO2: U3.3 (~WP/IO_{2}); also elsewhere on the board
QSPI_IO3: U3.7 (~HOLD/~RESET/IO_{3}); also elsewhere on the board
QSPI_NCS: R10.1, U3.1 (~CS); also elsewhere on the board
SPI1_MISO: U4.1 (AP_SDO); also elsewhere on the board
SPI1_MOSI: U4.14 (AP_SDI); also elsewhere on the board
SPI1_SCK: U4.13 (AP_SCLK); also elsewhere on the board

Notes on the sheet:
03 | Memory and sensors
U4: single-interface 4-wire SPI. Keep INT2 open; unused auxiliary pads grounded.
Firmware must disable the default pulls on tied auxiliary pads (DS-000577 section 4.1).
U5: PS high selects I2C; CSB low. SDO has a 10k pulldown, not a direct ground short.
Device detection is not sufficient: CRC, bus fault recovery and sample continuity still need tests.

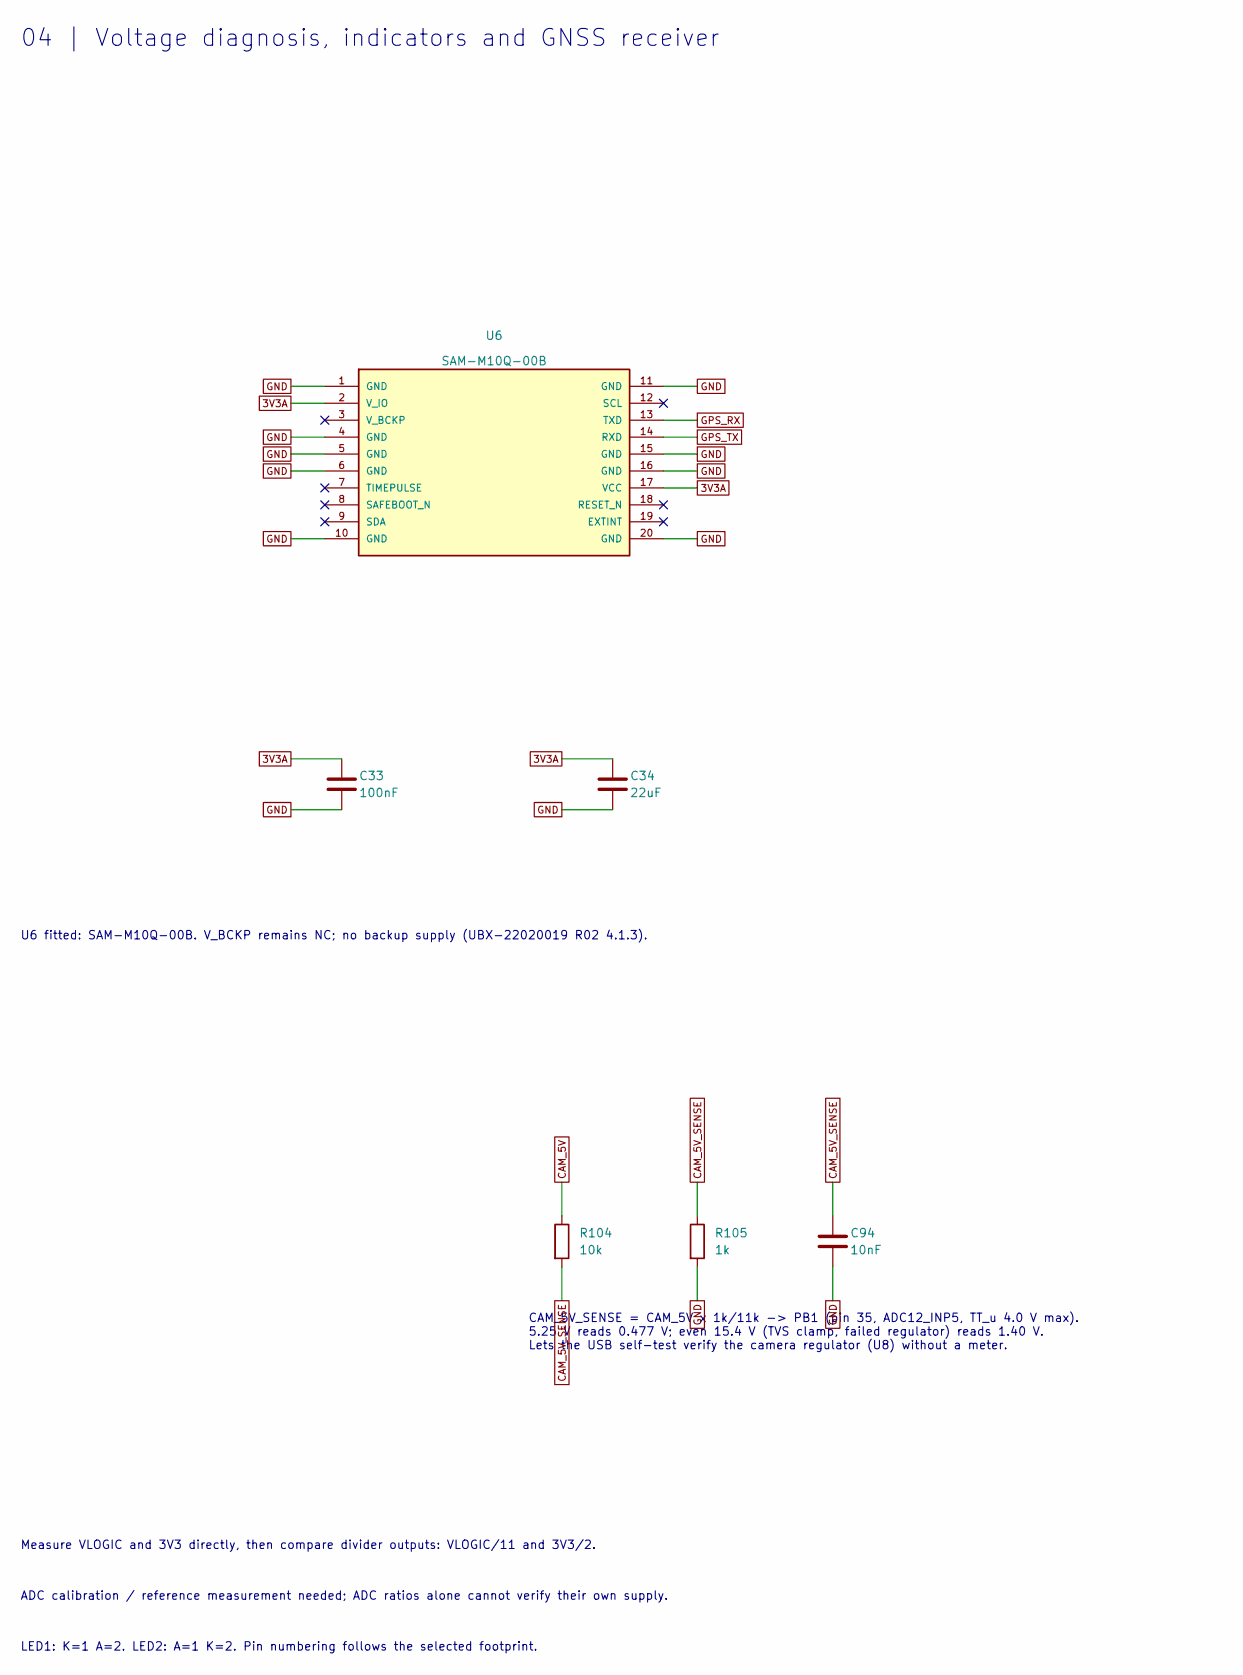
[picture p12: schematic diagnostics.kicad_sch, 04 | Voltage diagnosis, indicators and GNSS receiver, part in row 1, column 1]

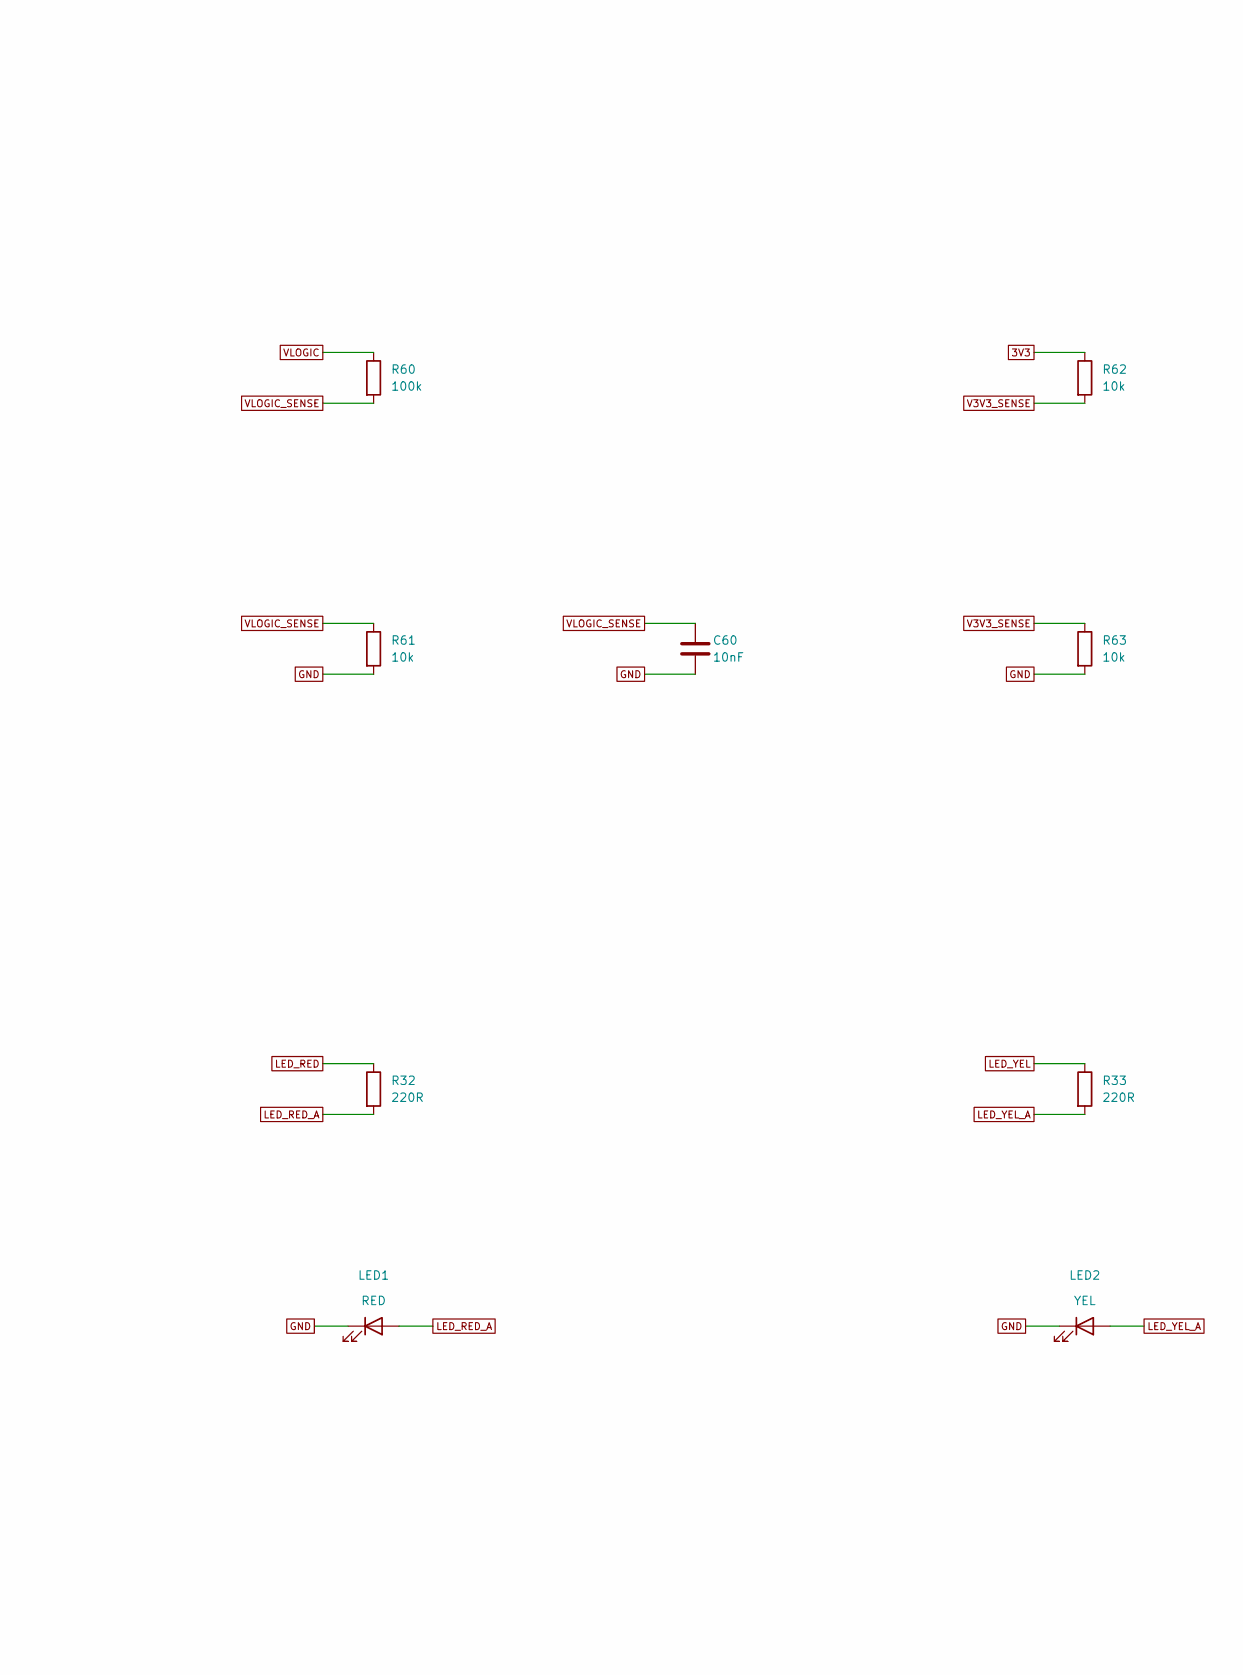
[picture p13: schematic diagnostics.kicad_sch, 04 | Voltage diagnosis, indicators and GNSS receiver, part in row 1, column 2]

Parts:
C33: 100nF; C0402; LCSC C1525
C34: 22uF; C0805; LCSC C45783
C60, C94: 10nF; C0603; LCSC C57112
LED1: RED; M3_NCD0805R1_K1; Manufacturer Part NCD0805R1; LCSC C84256
LED2: YEL; M3_KT0805Y_A1; Manufacturer Part KT-0805Y; LCSC C2296
R32, R33: 220R; R0805; LCSC C17557
R60: 100k; R0402; LCSC C25741
R61, R62, R63, R104: 10k; R0402; LCSC C25744
R105: 1k; R0402; LCSC C11702
U6: SAM-M10Q-00B; LCC-20_L15.5-W15.5-P1.90_SAM-M10Q-00B; LCSC C5443880

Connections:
3V3: R62.1; also elsewhere on the board
3V3A: C33.1, C34.1, U6.2 (V_IO), U6.17 (VCC); also elsewhere on the board
CAM_5V: R104.1; also elsewhere on the board
CAM_5V_SENSE: C94.1, R104.2, R105.1; also elsewhere on the board
GND: C33.2, C34.2, C60.2, C94.2, LED1.1 (K), LED2.2 (K), R61.2, R63.2, R105.2, U6.1 (GND), U6.4 (GND), U6.5 (GND), U6.6 (GND), U6.10 (GND), U6.11 (GND), U6.15 (GND), U6.16 (GND), U6.20 (GND); also elsewhere on the board
GPS_RX: U6.13 (TXD); also elsewhere on the board
GPS_TX: U6.14 (RXD); also elsewhere on the board
LED_RED: R32.1; also elsewhere on the board
LED_RED_A: LED1.2 (A), R32.2
LED_YEL: R33.1; also elsewhere on the board
LED_YEL_A: LED2.1 (A), R33.2
V3V3_SENSE: R62.2, R63.1; also elsewhere on the board
VLOGIC: R60.1; also elsewhere on the board
VLOGIC_SENSE: C60.1, R60.2, R61.1; also elsewhere on the board

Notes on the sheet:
04 | Voltage diagnosis, indicators and GNSS receiver
U6 fitted: SAM-M10Q-00B. V_BCKP remains NC; no backup supply (UBX-22020019 R02 4.1.3).
Measure VLOGIC and 3V3 directly, then compare divider outputs: VLOGIC/11 and 3V3/2.
ADC calibration / reference measurement needed; ADC ratios alone cannot verify their own supply.
LED1: K=1 A=2. LED2: A=1 K=2. Pin numbering follows the selected footprint.
CAM_5V_SENSE = CAM_5V x 1k/11k -> PB1 (pin 35, ADC12_INP5, TT_u 4.0 V max). 5.25 V reads 0.477 V; even 15.4 V (TVS clamp, failed regulator) reads 1.40 V. Lets the USB self-test verify the camera regulator (U8) without a meter.

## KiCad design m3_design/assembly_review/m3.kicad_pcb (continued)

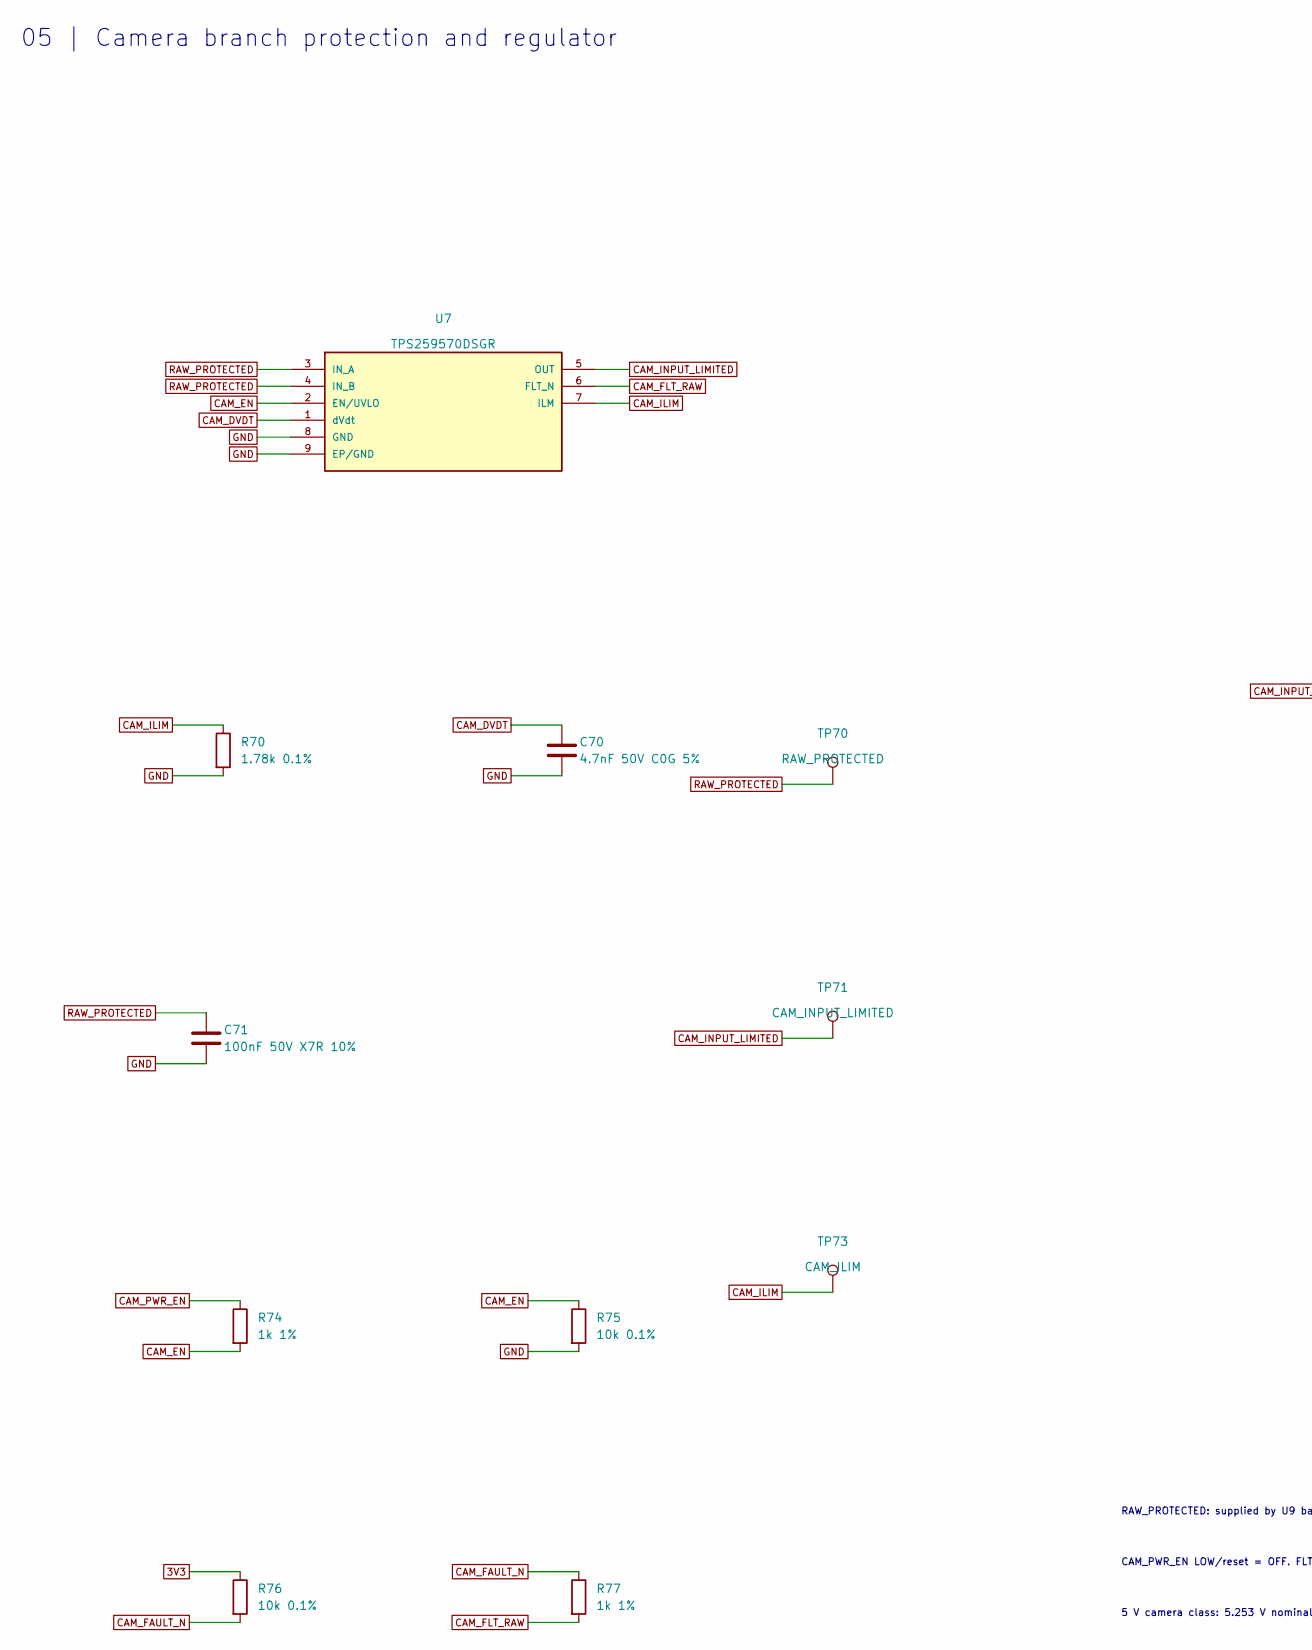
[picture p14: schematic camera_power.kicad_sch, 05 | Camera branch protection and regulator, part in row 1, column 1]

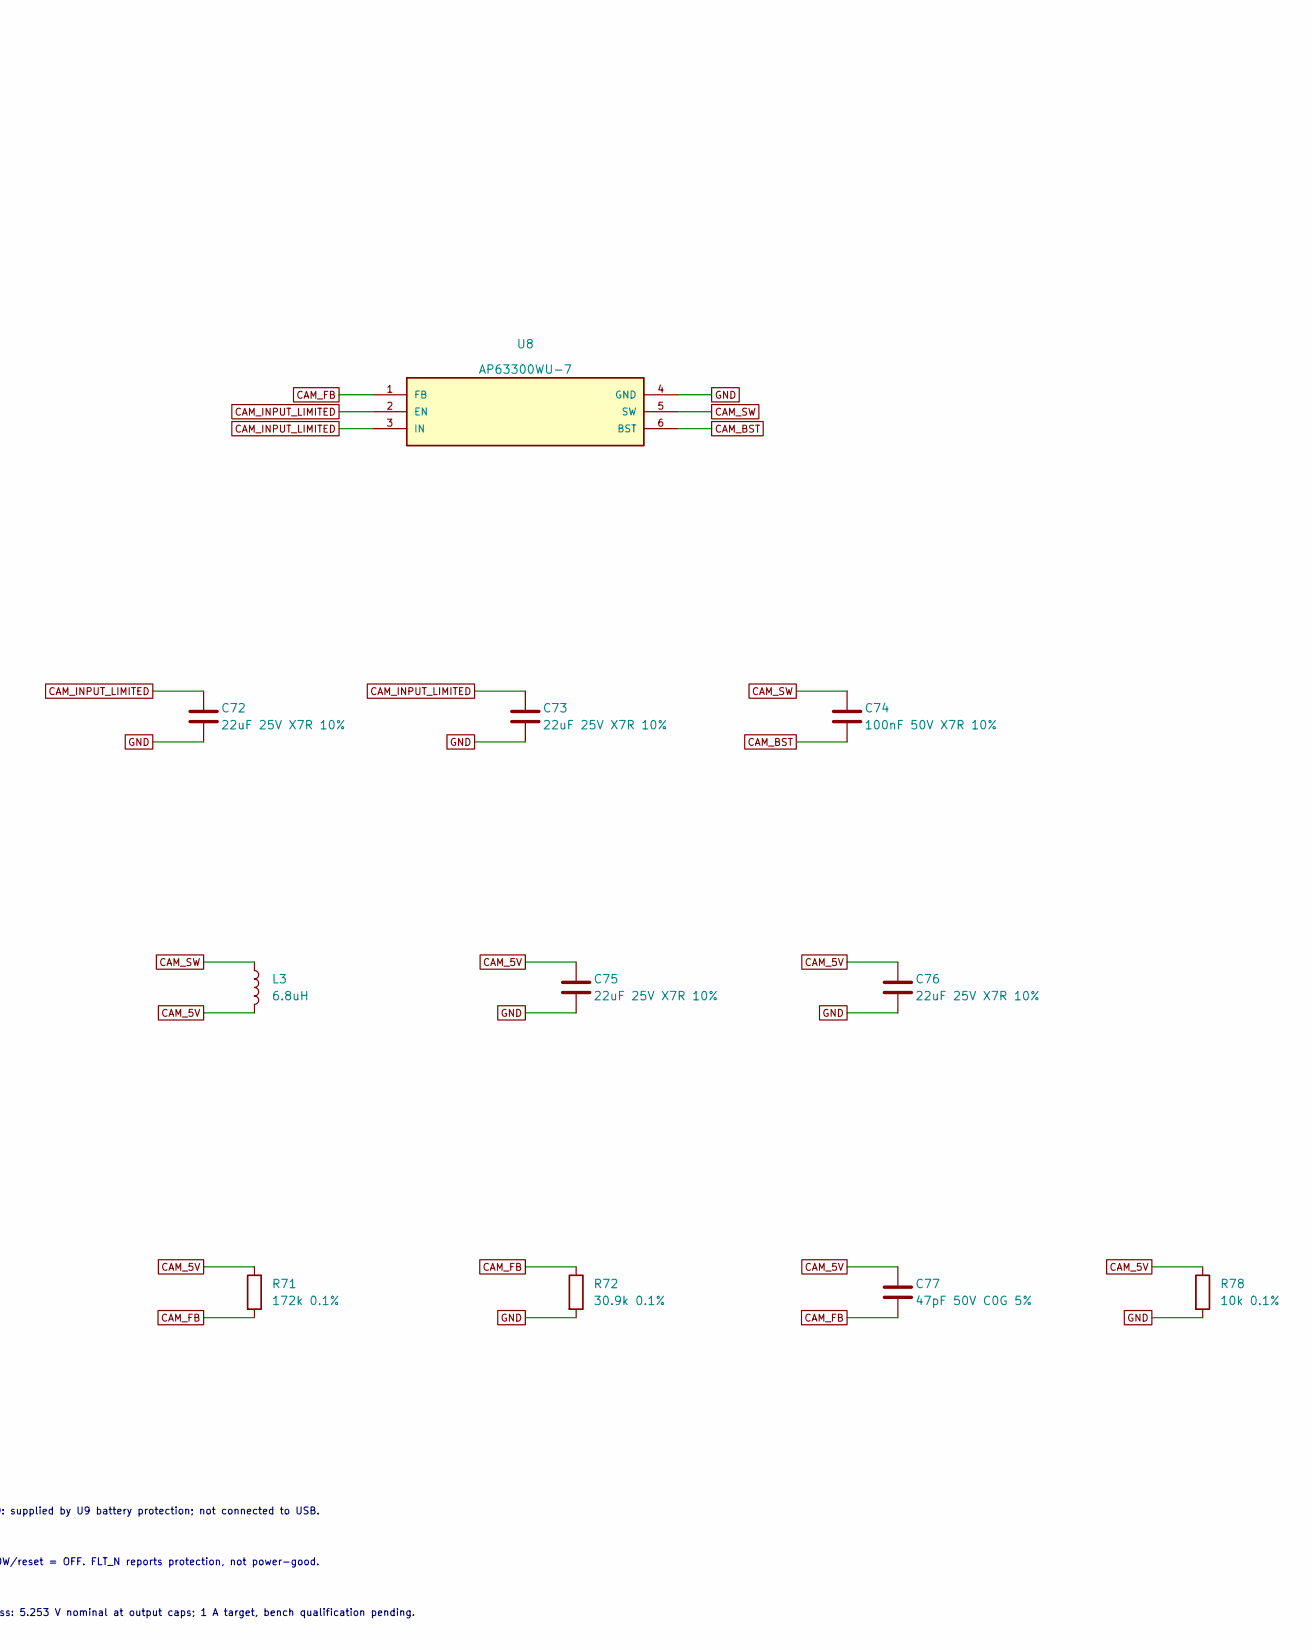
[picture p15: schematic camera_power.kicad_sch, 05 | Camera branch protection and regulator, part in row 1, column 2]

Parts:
C70: 4.7nF 50V C0G 5%; C_0603_1608Metric; Manufacturer Part GRM1885C1H472JA01D; LCSC C85980
C71, C74: 100nF 50V X7R 10%; C_0603_1608Metric; Manufacturer Part CL10B104KB8NNNC; LCSC C1591
C72, C73, C75, C76: 22uF 25V X7R 10%; M3_GRM32_1210; Manufacturer Part GRM32ER71E226KE15L; LCSC C21397
C77: 47pF 50V C0G 5%; C_0603_1608Metric; Manufacturer Part CL10C470JB8NNNC; LCSC C1671
L3: 6.8uH; M3_SRP5030TA; Manufacturer Part SRP5030T-6R8M; LCSC C1329837
R70: 1.78k 0.1%; R_0603_1608Metric; Manufacturer Part RT0603BRD071K78L; LCSC C861207
R71: 172k 0.1%; R_0603_1608Metric; Manufacturer Part RT0603BRD07172KL; LCSC C861162
R72: 30.9k 0.1%; R_0603_1608Metric; Manufacturer Part RT0603BRD0730K9L; LCSC C861313
R74, R77: 1k 1%; R_0603_1608Metric; Manufacturer Part RC0603FR-071KL; LCSC C22548
R75, R76, R78: 10k 0.1%; R_0603_1608Metric; Manufacturer Part RT0603BRD0710KL; LCSC C95204
TP70: RAW_PROTECTED; M3_TestPad_1.5
TP71: CAM_INPUT_LIMITED; M3_TestPad_1.5
TP73: CAM_ILIM; M3_TestPad_1.5
U7: TPS259570DSGR; M3_TPS2595_DSG; LCSC C1849463
U8: AP63300WU-7; M3_AP63200_TSOT26; LCSC C2158012

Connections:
3V3: R76.1; also elsewhere on the board
CAM_5V: C75.1, C76.1, C77.1, L3.2, R71.1, R78.1; also elsewhere on the board
CAM_BST: C74.2, U8.6 (BST)
CAM_DVDT: C70.1, U7.1 (dVdt)
CAM_EN: R74.2, R75.1, U7.2 (EN/UVLO)
CAM_FAULT_N: R76.2, R77.1; also elsewhere on the board
CAM_FB: C77.2, R71.2, R72.1, U8.1 (FB)
CAM_FLT_RAW: R77.2, U7.6 (FLT_N)
CAM_ILIM: R70.1, TP73.1, U7.7 (ILM)
CAM_INPUT_LIMITED: C72.1, C73.1, TP71.1, U7.5 (OUT), U8.2 (EN), U8.3 (IN)
CAM_PWR_EN: R74.1; also elsewhere on the board
CAM_SW: C74.1, L3.1, U8.5 (SW)
GND: C70.2, C71.2, C72.2, C73.2, C75.2, C76.2, R70.2, R72.2, R75.2, R78.2, U7.8 (GND), U7.9 (EP/GND), U8.4 (GND); also elsewhere on the board
RAW_PROTECTED: C71.1, TP70.1, U7.3 (IN_A), U7.4 (IN_B); also elsewhere on the board

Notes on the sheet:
05 | Camera branch protection and regulator
RAW_PROTECTED: supplied by U9 battery protection; not connected to USB.
CAM_PWR_EN LOW/reset = OFF. FLT_N reports protection, not power-good.
5 V camera class: 5.253 V nominal at output caps; 1 A target, bench qualification pending.

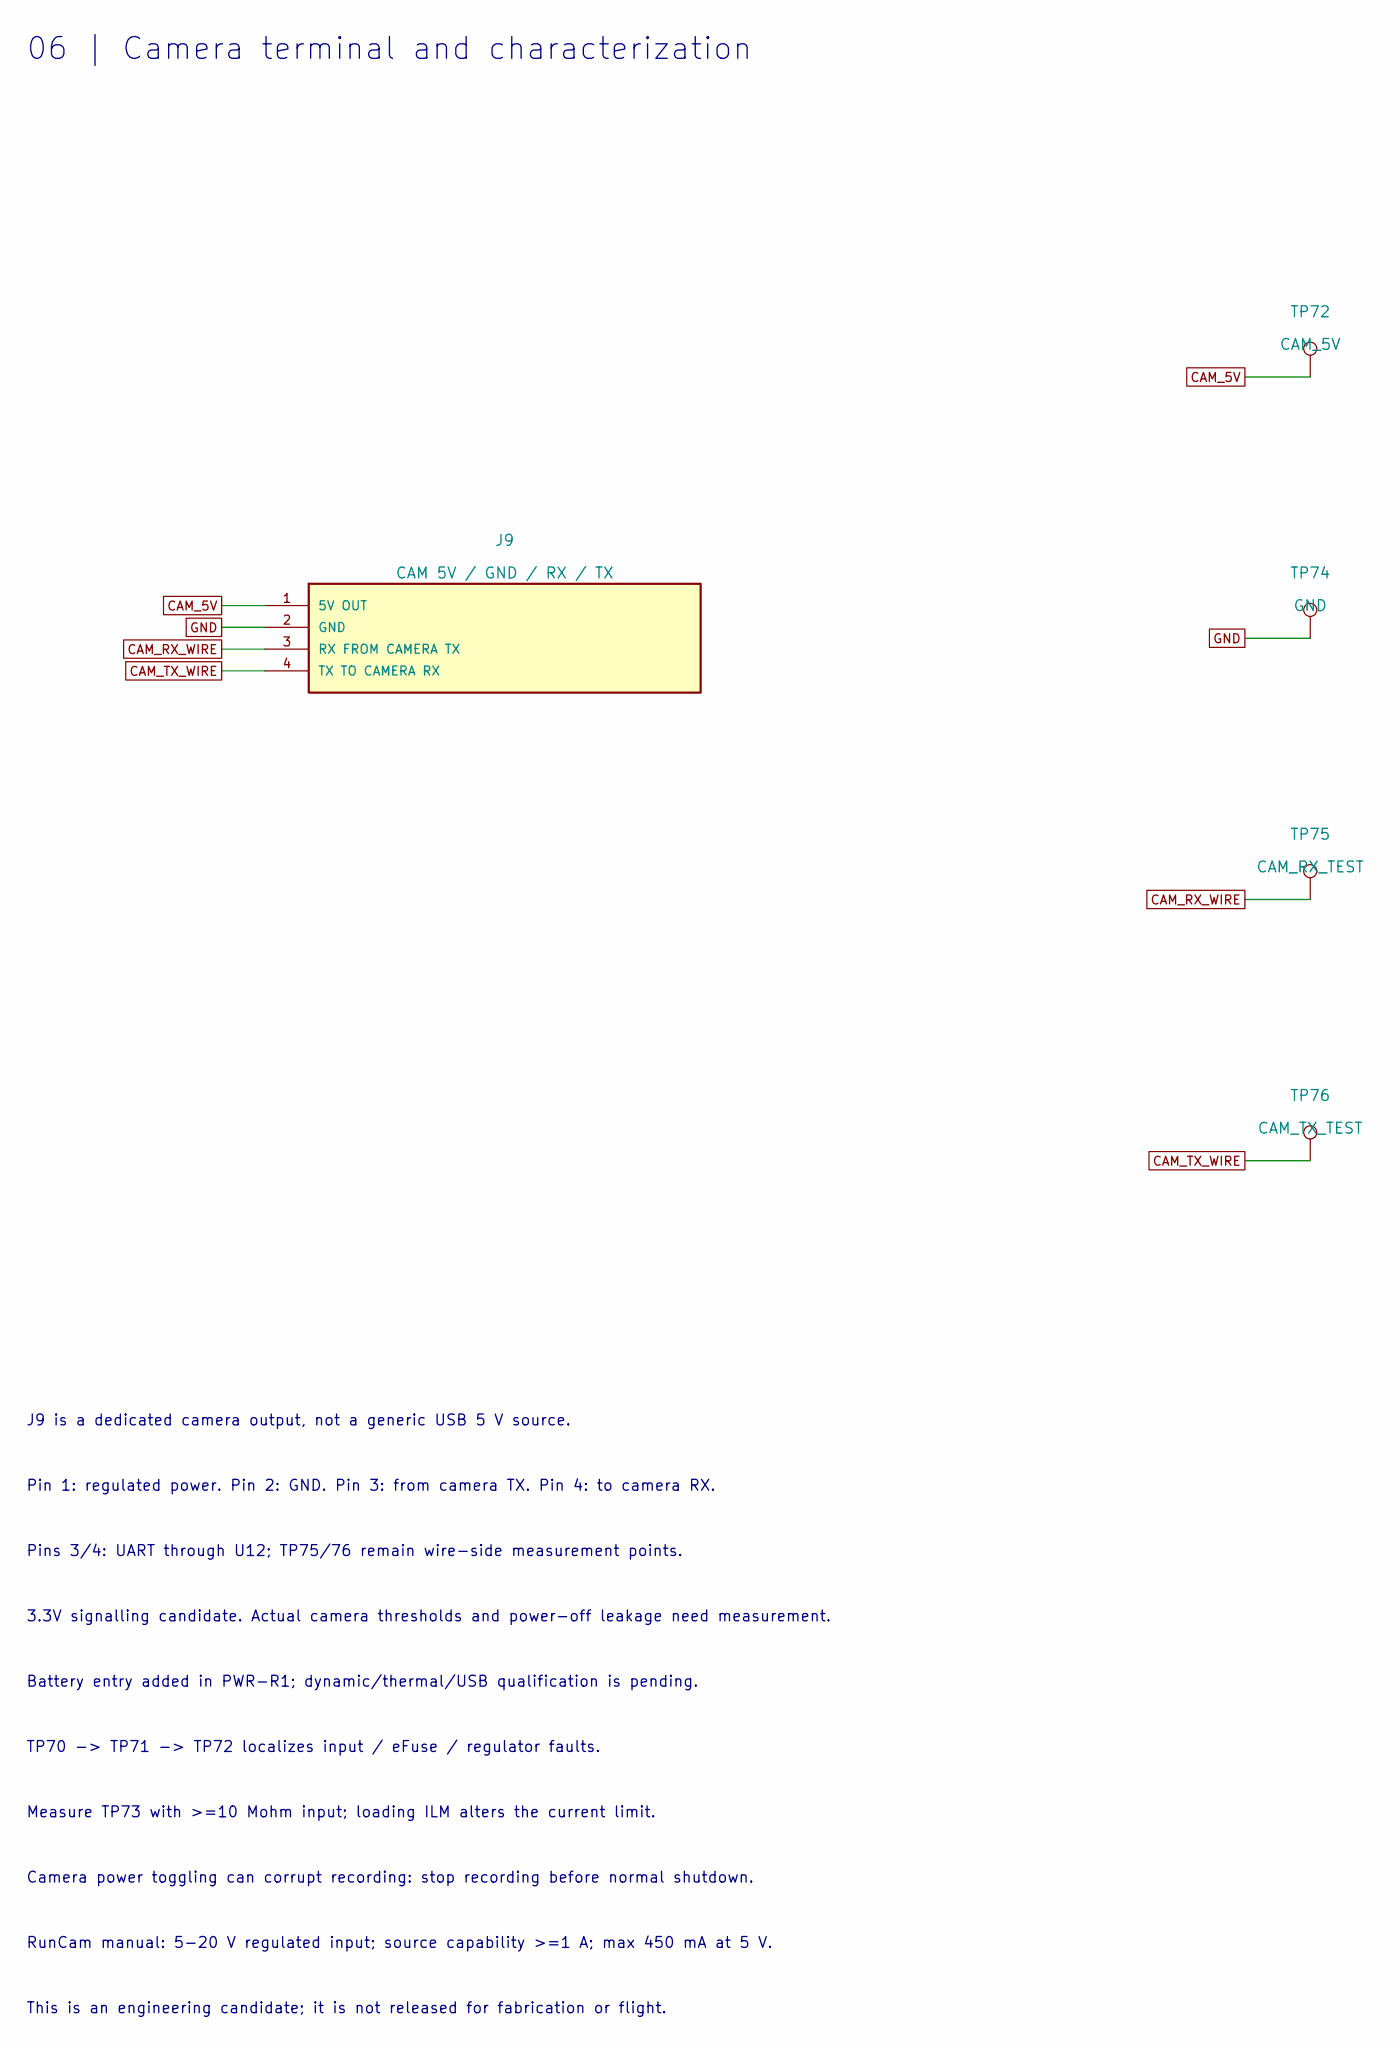
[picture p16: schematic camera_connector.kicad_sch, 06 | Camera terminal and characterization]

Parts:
J9: CAM 5V / GND / RX / TX; M3_DB128V_4P; LCSC C2915641
TP72: CAM_5V; M3_TestPad_1.5
TP74: GND; M3_TestPad_1.5
TP75: CAM_RX_TEST; M3_TestPad_1.5
TP76: CAM_TX_TEST; M3_TestPad_1.5

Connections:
CAM_5V: J9.1 (5V OUT), TP72.1; also elsewhere on the board
CAM_RX_WIRE: J9.3 (RX FROM CAMERA TX), TP75.1; also elsewhere on the board
CAM_TX_WIRE: J9.4 (TX TO CAMERA RX), TP76.1; also elsewhere on the board
GND: J9.2 (GND), TP74.1; also elsewhere on the board

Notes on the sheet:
06 | Camera terminal and characterization
J9 is a dedicated camera output, not a generic USB 5 V source.
Pin 1: regulated power. Pin 2: GND. Pin 3: from camera TX. Pin 4: to camera RX.
Pins 3/4: UART through U12; TP75/76 remain wire-side measurement points.
3.3V signalling candidate. Actual camera thresholds and power-off leakage need measurement.
Battery entry added in PWR-R1; dynamic/thermal/USB qualification is pending.
TP70 -> TP71 -> TP72 localizes input / eFuse / regulator faults.
Measure TP73 with >=10 Mohm input; loading ILM alters the current limit.
Camera power toggling can corrupt recording: stop recording before normal shutdown.
RunCam manual: 5-20 V regulated input; source capability >=1 A; max 450 mA at 5 V.
This is an engineering candidate; it is not released for fabrication or flight.

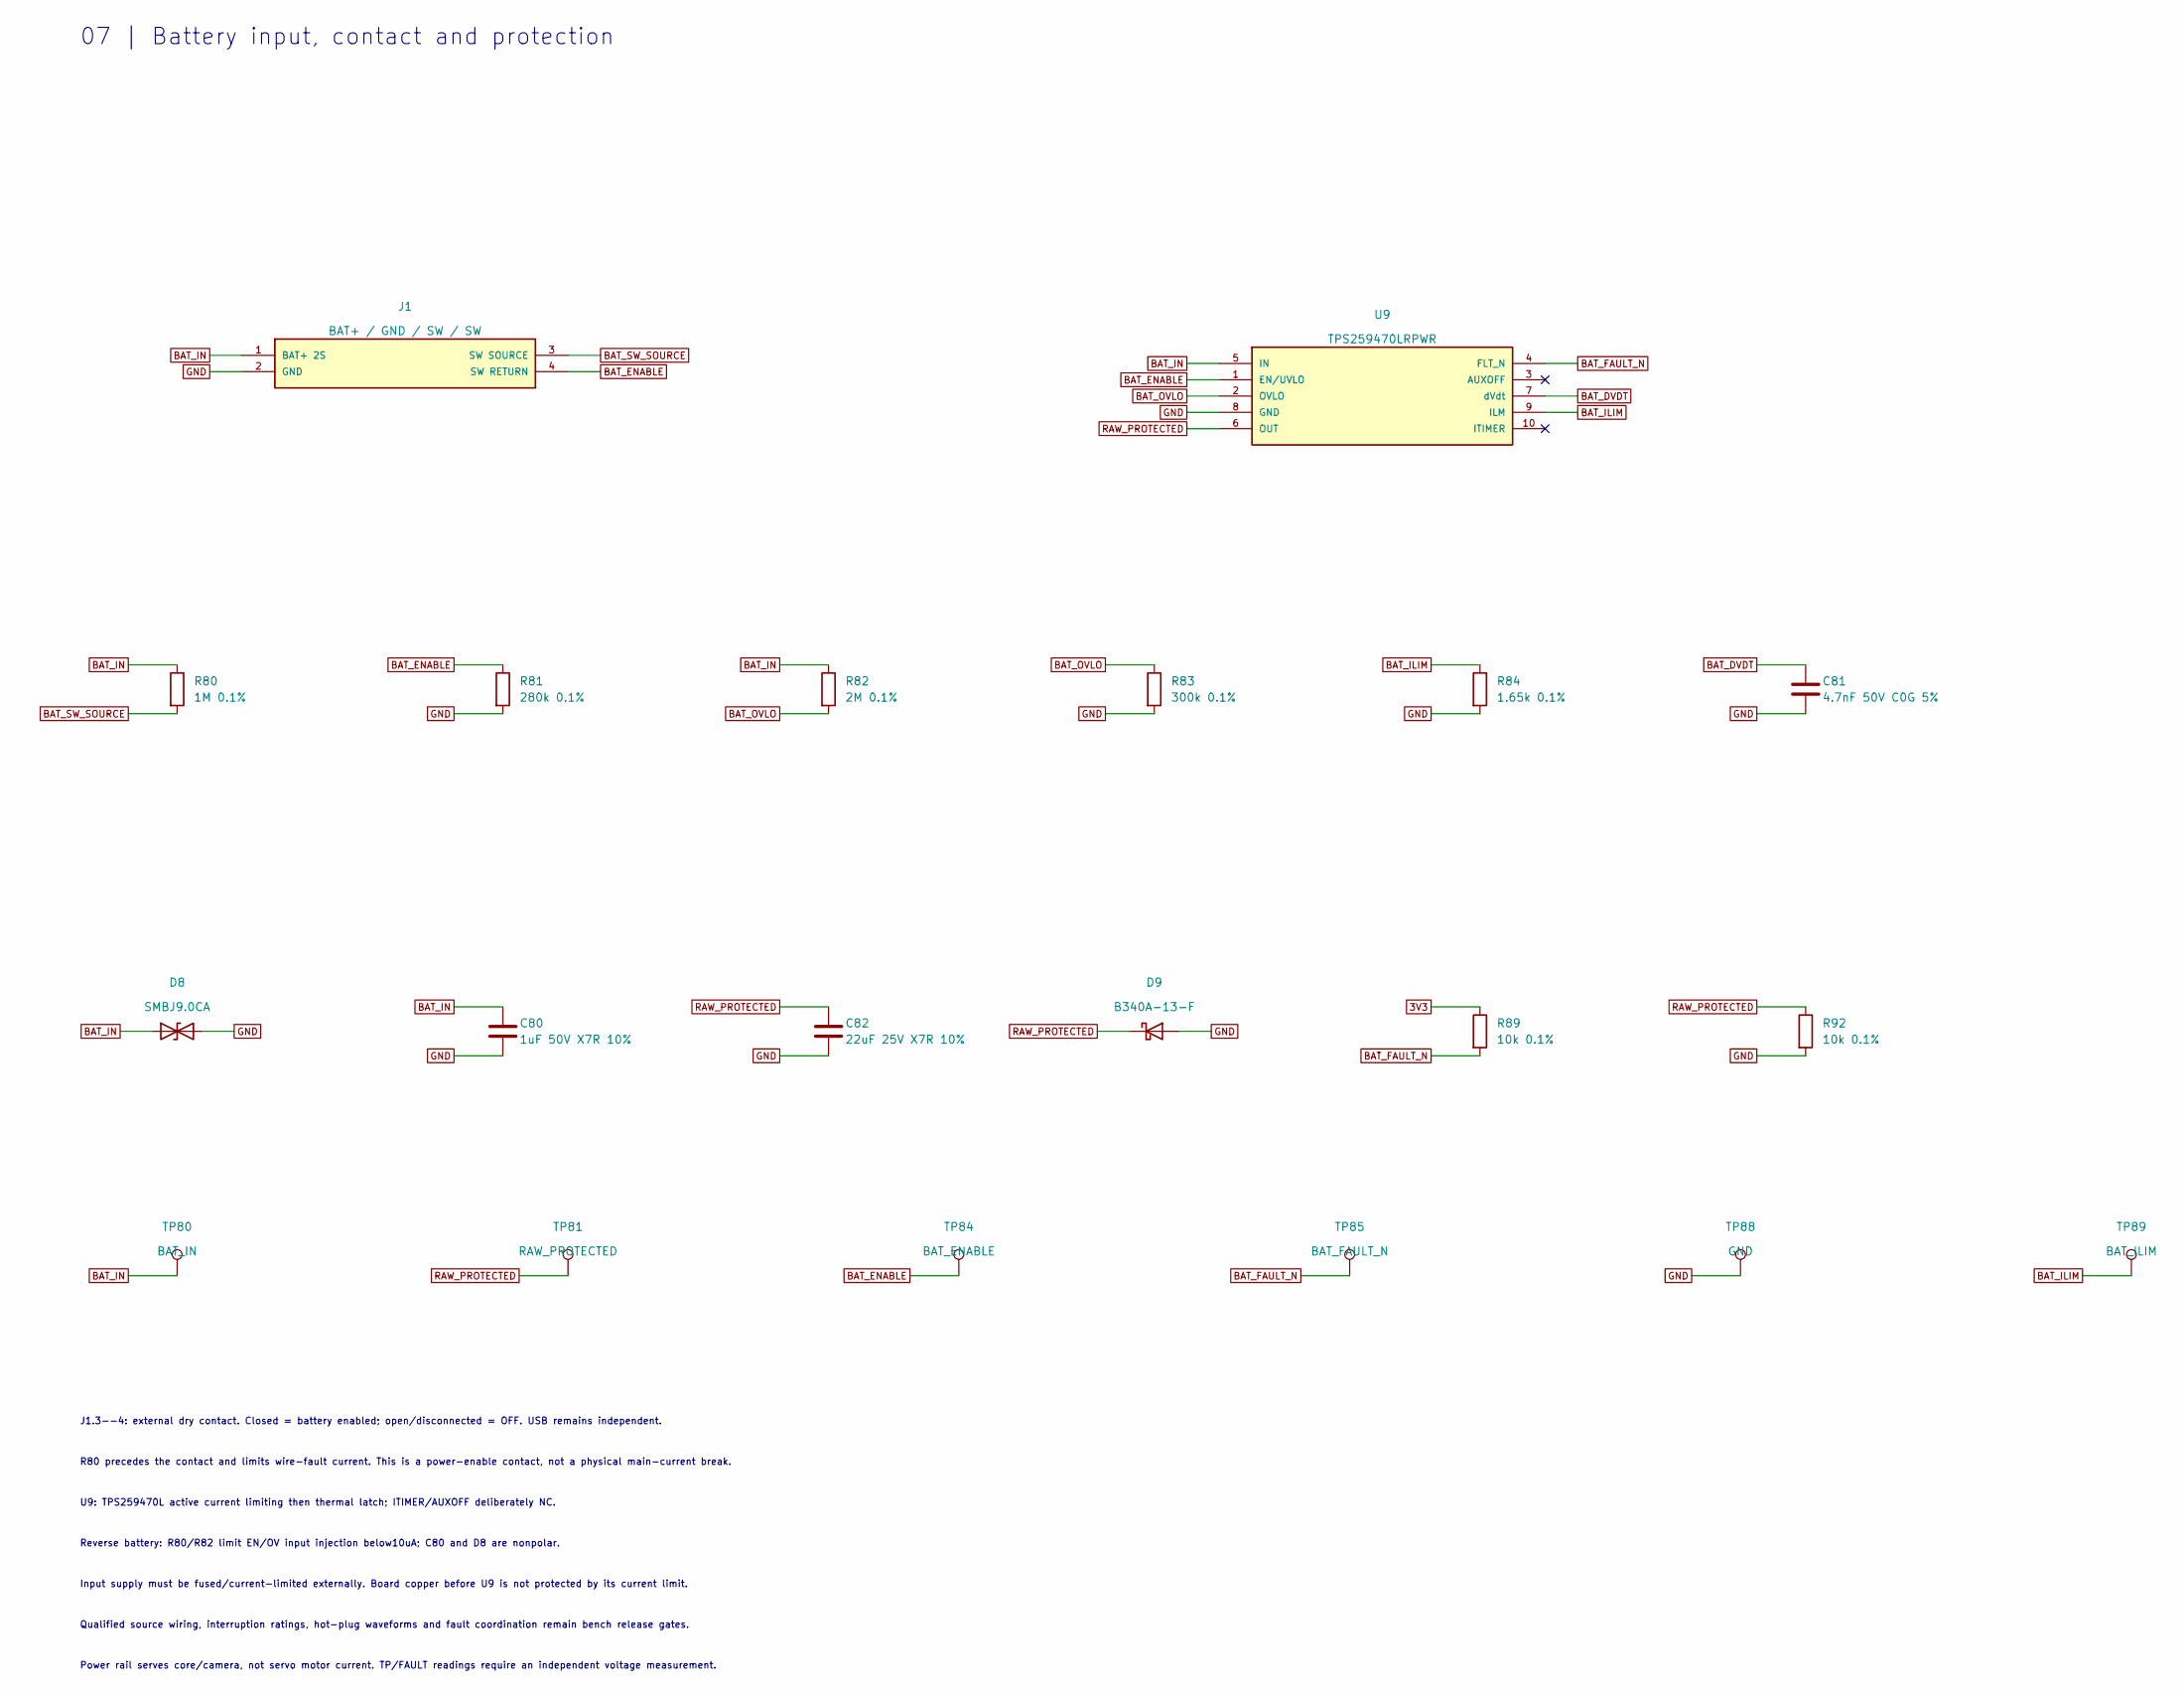
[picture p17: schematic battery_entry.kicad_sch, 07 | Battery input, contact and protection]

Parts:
C80: 1uF 50V X7R 10%; C_1206_3216Metric; Manufacturer Part CL31B105KBHNNNE; LCSC C1848
C81: 4.7nF 50V C0G 5%; C_0603_1608Metric; Manufacturer Part GRM1885C1H472JA01D; LCSC C85980
C82: 22uF 25V X7R 10%; M3_GRM32_1210; Manufacturer Part GRM32ER71E226KE15L; LCSC C21397
D8: SMBJ9.0CA; D_SMB; Manufacturer Part SMBJ9.0CA-13-F; LCSC C135111
D9: B340A-13-F; D_SMA; Manufacturer Part B340A-13-F; LCSC C85098
J1: BAT+ / GND / SW / SW; M3_DB128V_4P_Entry; LCSC C2915641
R80: 1M 0.1%; R_0603_1608Metric; Manufacturer Part RT0603BRD071ML; LCSC C326730
R81: 280k 0.1%; R_0603_1608Metric; Manufacturer Part RT0603BRD07280KL; LCSC C705755
R82: 2M 0.1%; R_0603_1608Metric; Manufacturer Part MCT0603MD2004BP500; LCSC C4241878
R83: 300k 0.1%; R_0603_1608Metric; Manufacturer Part RT0603BRD07300KL; LCSC C705762
R84: 1.65k 0.1%; R_0603_1608Metric; Manufacturer Part RT0603BRD071K65L; LCSC C705743
R89, R92: 10k 0.1%; R_0603_1608Metric; Manufacturer Part RT0603BRD0710KL; LCSC C95204
TP80: BAT_IN; M3_TestPad_1.5
TP81: RAW_PROTECTED; M3_TestPad_1.5
TP84: BAT_ENABLE; M3_TestPad_1.5
TP85: BAT_FAULT_N; M3_TestPad_1.5
TP88: GND; M3_TestPad_1.5
TP89: BAT_ILIM; M3_TestPad_1.5
U9: TPS259470LRPWR; M3_TPS25947_RPW; LCSC C3662793

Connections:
3V3: R89.1; also elsewhere on the board
BAT_DVDT: C81.1, U9.7 (dVdt)
BAT_ENABLE: J1.4 (SW RETURN), R81.1, TP84.1, U9.1 (EN/UVLO)
BAT_FAULT_N: R89.2, TP85.1, U9.4 (FLT_N); also elsewhere on the board
BAT_ILIM: R84.1, TP89.1, U9.9 (ILM)
BAT_IN: C80.1, D8.1 (A1), J1.1 (BAT+ 2S), R80.1, R82.1, TP80.1, U9.5 (IN); also elsewhere on the board
BAT_OVLO: R82.2, R83.1, U9.2 (OVLO)
BAT_SW_SOURCE: J1.3 (SW SOURCE), R80.2
GND: C80.2, C81.2, C82.2, D8.2 (A2), D9.2 (A), J1.2 (GND), R81.2, R83.2, R84.2, R92.2, TP88.1, U9.8 (GND); also elsewhere on the board
RAW_PROTECTED: C82.1, D9.1 (K), R92.1, TP81.1, U9.6 (OUT); also elsewhere on the board

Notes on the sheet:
07 | Battery input, contact and protection
J1.3--4: external dry contact. Closed = battery enabled; open/disconnected = OFF. USB remains independent.
R80 precedes the contact and limits wire-fault current. This is a power-enable contact, not a physical main-current break.
U9: TPS259470L active current limiting then thermal latch; ITIMER/AUXOFF deliberately NC.
Reverse battery: R80/R82 limit EN/OV input injection below10uA; C80 and D8 are nonpolar.
Input supply must be fused/current-limited externally. Board copper before U9 is not protected by its current limit.
Qualified source wiring, interruption ratings, hot-plug waveforms and fault coordination remain bench release gates.
Power rail serves core/camera, not servo motor current. TP/FAULT readings require an independent voltage measurement.

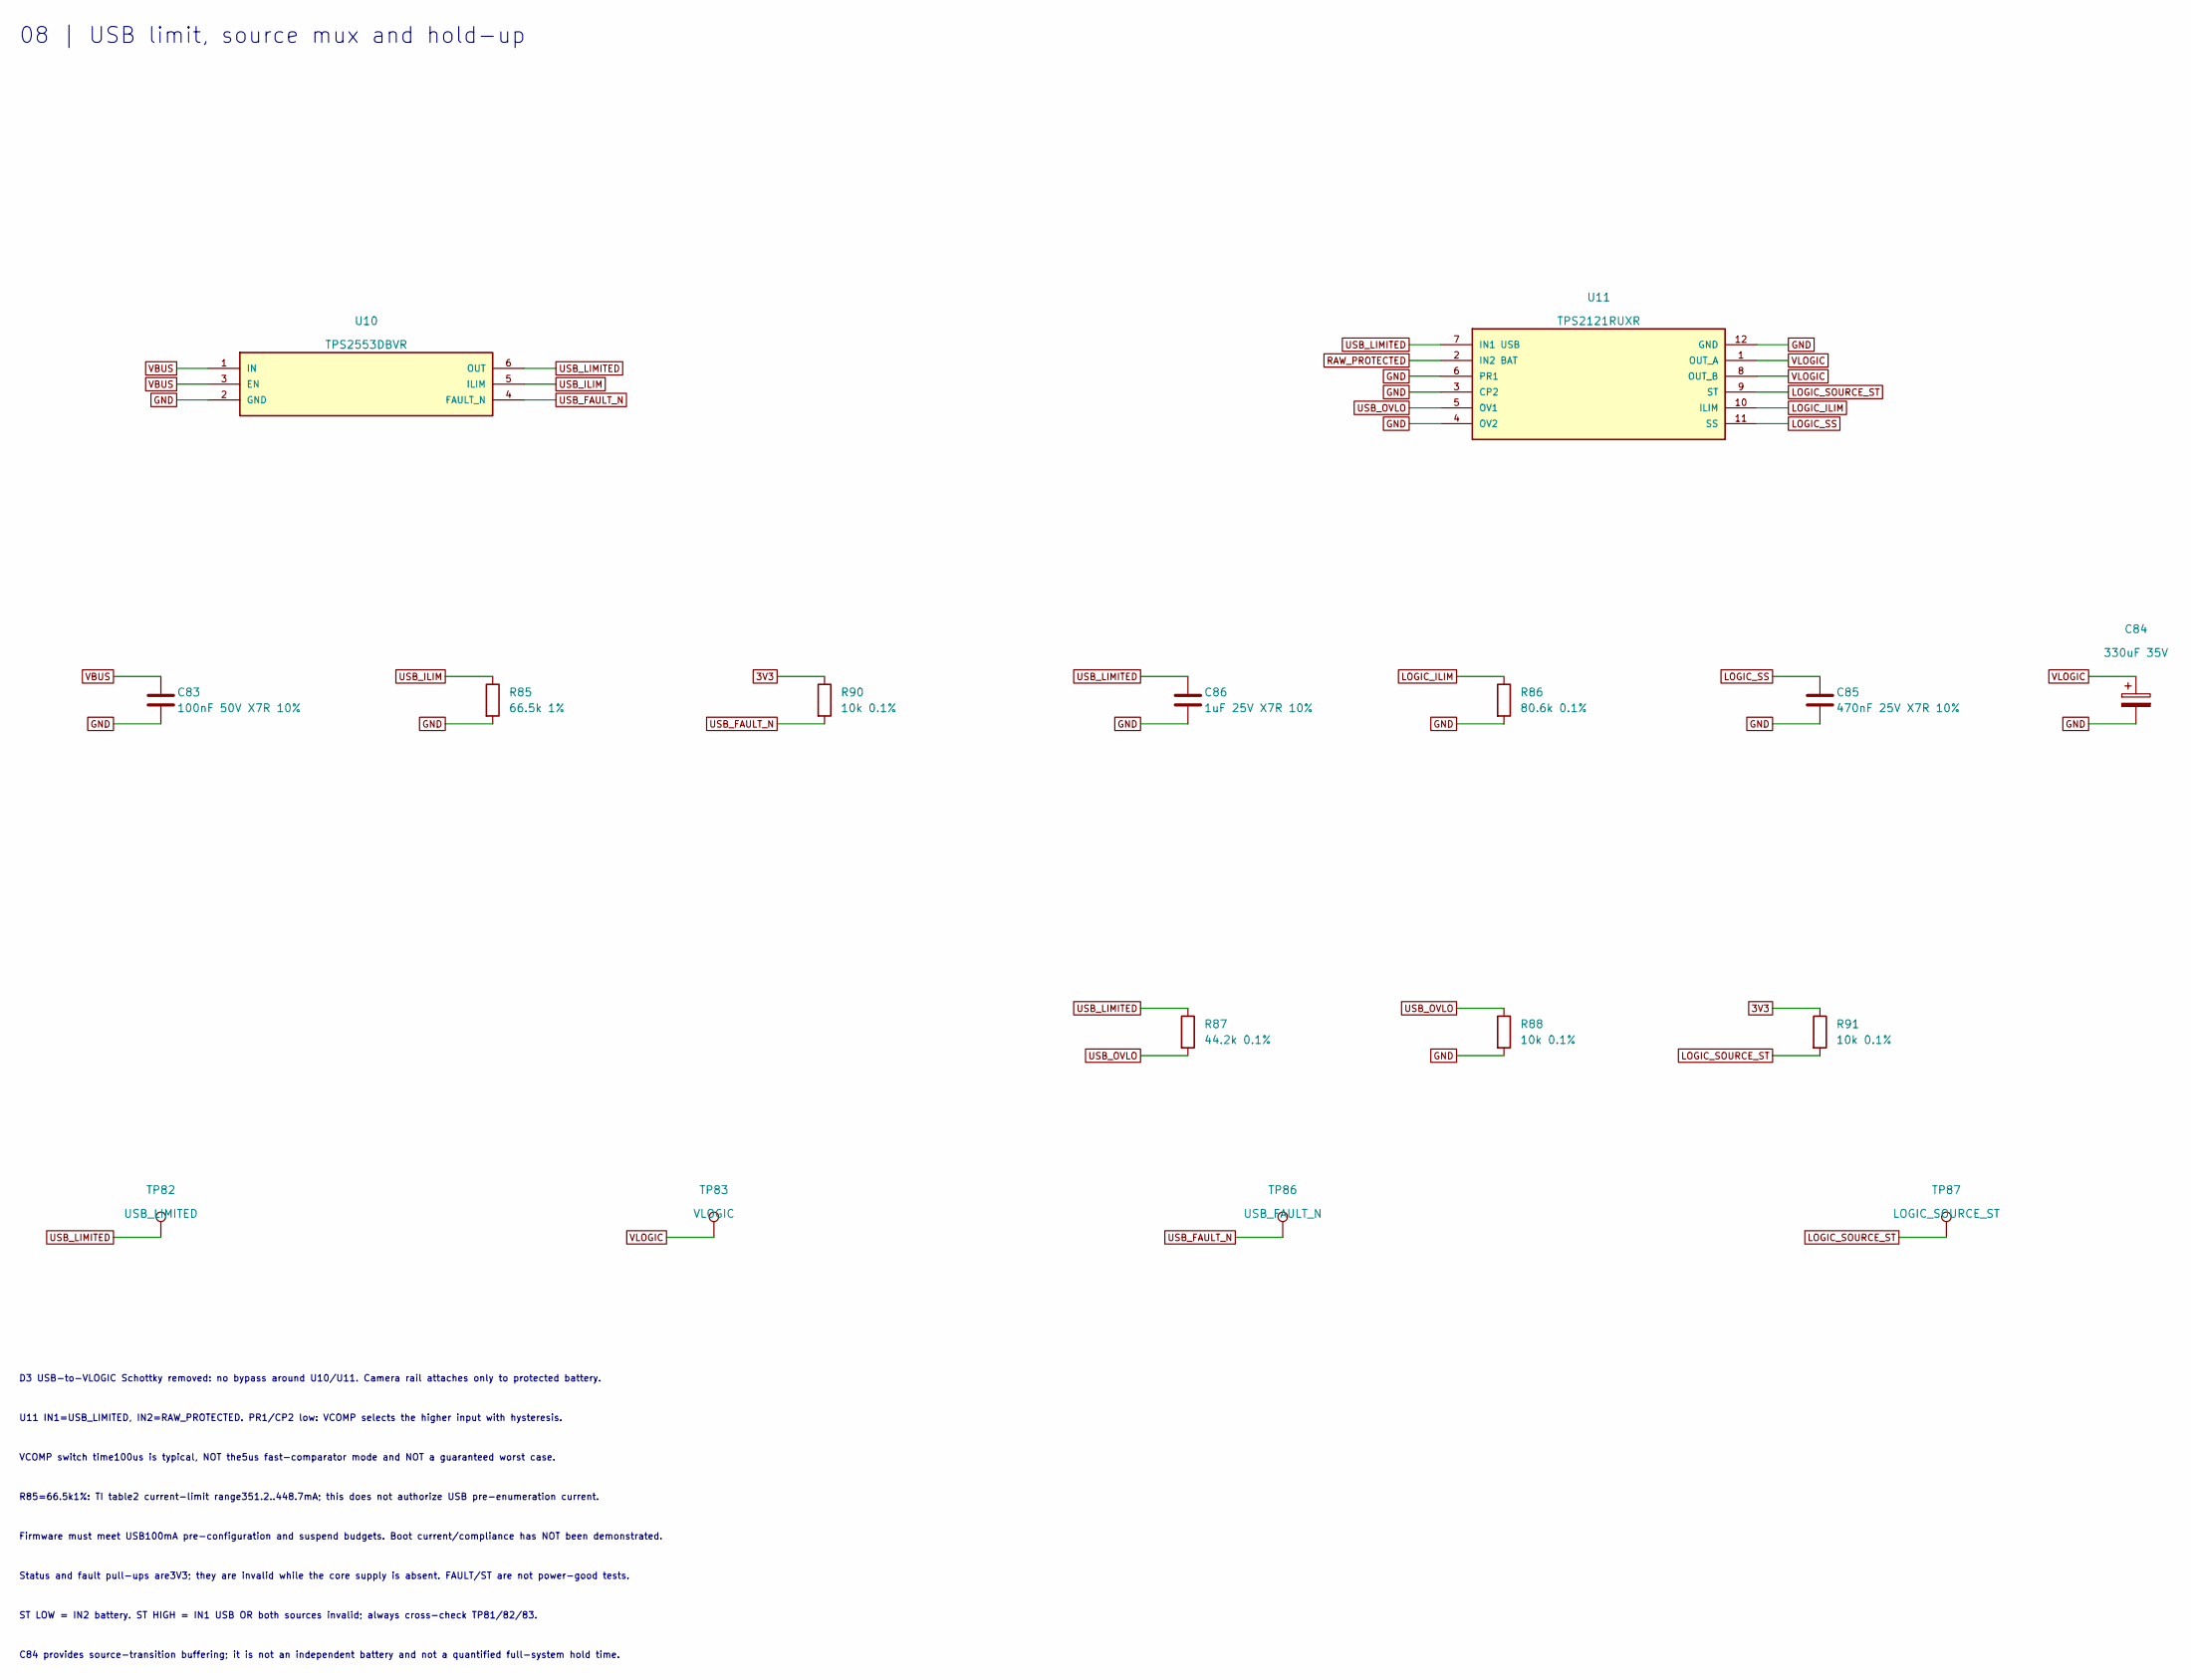
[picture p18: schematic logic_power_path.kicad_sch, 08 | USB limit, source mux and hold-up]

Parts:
C83: 100nF 50V X7R 10%; C_0603_1608Metric; Manufacturer Part CL10B104KB8NNNC; LCSC C1591
C84: 330uF 35V; M3_OSCON_F12; Manufacturer Part 35SVPK330M; LCSC C178373
C85: 470nF 25V X7R 10%; C_0603_1608Metric; Manufacturer Part CL10B474KA8NNNC; LCSC C1623
C86: 1uF 25V X7R 10%; C_0603_1608Metric; Manufacturer Part CL10B105KA8NNNC; LCSC C29936
R85: 66.5k 1%; R_0603_1608Metric; Manufacturer Part RC0603FR-0766K5L; LCSC C137691
R86: 80.6k 0.1%; R_0603_1608Metric; Manufacturer Part RT0603BRD0780K6L; LCSC C861568
R87: 44.2k 0.1%; R_0603_1608Metric; Manufacturer Part RT0603BRD0744K2L; LCSC C861410
R88, R90, R91: 10k 0.1%; R_0603_1608Metric; Manufacturer Part RT0603BRD0710KL; LCSC C95204
TP82: USB_LIMITED; M3_TestPad_1.5
TP83: VLOGIC; M3_TestPad_1.5
TP86: USB_FAULT_N; M3_TestPad_1.5
TP87: LOGIC_SOURCE_ST; M3_TestPad_1.5
U10: TPS2553DBVR; M3_TPS2553_DBV; LCSC C55266
U11: TPS2121RUXR; M3_TPS2121_RUX; LCSC C485916

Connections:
3V3: R90.1, R91.1; also elsewhere on the board
GND: C83.2, C84.2, C85.2, C86.2, R85.2, R86.2, R88.2, U10.2 (GND), U11.3 (CP2), U11.4 (OV2), U11.6 (PR1), U11.12 (GND); also elsewhere on the board
LOGIC_ILIM: R86.1, U11.10 (ILIM)
LOGIC_SOURCE_ST: R91.2, TP87.1, U11.9 (ST); also elsewhere on the board
LOGIC_SS: C85.1, U11.11 (SS)
RAW_PROTECTED: U11.2 (IN2 BAT); also elsewhere on the board
USB_FAULT_N: R90.2, TP86.1, U10.4 (FAULT_N); also elsewhere on the board
USB_ILIM: R85.1, U10.5 (ILIM)
USB_LIMITED: C86.1, R87.1, TP82.1, U10.6 (OUT), U11.7 (IN1 USB)
USB_OVLO: R87.2, R88.1, U11.5 (OV1)
VBUS: C83.1, U10.1 (IN), U10.3 (EN); also elsewhere on the board
VLOGIC: C84.1, TP83.1, U11.1 (OUT_A), U11.8 (OUT_B); also elsewhere on the board

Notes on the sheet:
08 | USB limit, source mux and hold-up
D3 USB-to-VLOGIC Schottky removed: no bypass around U10/U11. Camera rail attaches only to protected battery.
U11 IN1=USB_LIMITED, IN2=RAW_PROTECTED. PR1/CP2 low: VCOMP selects the higher input with hysteresis.
VCOMP switch time100us is typical, NOT the5us fast-comparator mode and NOT a guaranteed worst case.
R85=66.5k1%: TI table2 current-limit range351.2..448.7mA; this does not authorize USB pre-enumeration current.
Firmware must meet USB100mA pre-configuration and suspend budgets. Boot current/compliance has NOT been demonstrated.
Status and fault pull-ups are3V3; they are invalid while the core supply is absent. FAULT/ST are not power-good tests.
ST LOW = IN2 battery. ST HIGH = IN1 USB OR both sources invalid; always cross-check TP81/82/83.
C84 provides source-transition buffering; it is not an independent battery and not a quantified full-system hold time.

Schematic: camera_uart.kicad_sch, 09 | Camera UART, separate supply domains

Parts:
C90, C93: 100nF 50V X7R 10%; C_0603_1608Metric; Manufacturer Part CL10B104KB8NNNC; LCSC C1591
C91: 1uF 50V X7R 10%; C_1206_3216Metric; Manufacturer Part CL31B105KBHNNNE; LCSC C1848
C92: 22uF 25V X7R 10%; M3_GRM32_1210; Manufacturer Part GRM32ER71E226KE15L; LCSC C21397
R100, R101, R103: 1k 1%; R_0603_1608Metric; Manufacturer Part RC0603FR-071KL; LCSC C22548
R102: 10k 0.1%; R_0603_1608Metric; Manufacturer Part RT0603BRD0710KL; LCSC C95204
TP90: CAM_IO_3V3; M3_TestPad_1.5
TP91: CAM_UART_OE; M3_TestPad_1.5
U12: TXU0202DCUR; M3_TXU0202_DCU; Manufacturer Part TXU0202DCUR; LCSC C5186957
U13: TPS70933DBVR; M3_TPS709_DBV; Manufacturer Part TPS70933DBVR; LCSC C89347

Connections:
3V3: C90.1, U12.3 (VCCA MCU); also elsewhere on the board
CAM_5V: C91.1, U13.1 (IN); also elsewhere on the board
CAM_IO_3V3: C92.1, C93.1, R103.1, TP90.1, U12.7 (VCCB CAMERA), U13.5 (OUT3.3V)
CAM_MCU_RX: U12.4 (A2Y RX OUTPUT); also elsewhere on the board
CAM_MCU_TX: U12.5 (A1 TX INPUT); also elsewhere on the board
CAM_RX_BUFFER: R100.2, U12.1 (B2 FROM CAMERA)
CAM_RX_WIRE: R100.1; also elsewhere on the board
CAM_TX_BUFFER: R101.1, U12.8 (B1Y TO CAMERA)
CAM_TX_WIRE: R101.2; also elsewhere on the board
CAM_UART_OE: R102.1, TP91.1, U12.6 (OE); also elsewhere on the board
GND: C90.2, C91.2, C92.2, C93.2, R102.2, R103.2, U12.2 (GND), U13.2 (GND); also elsewhere on the board

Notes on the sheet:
09 | Camera UART, separate supply domains
PB10/pin46 USART3_TX and PB11/pin47 USART3_RX use AF7. PC13/pin7 controls OE as GPIO.
U12 A-port=MCU3V3. B-port=U13 camera-derived3V3. Never substitute CAM5V for VCCB.
Reset: R102 holds OE LOW. Set TX idle HIGH before OE; disable OE before power-down.
U13 EN is internally biased: leave pin3 OPEN, not tied to IN. Pin4 is NC.
UART is 3.3V, not RS232. TXU input operating range0..5.5V is not a cable battery-short rating.
Camera VIH/VIL/VOH/VOL and timing remain unmeasured. Verify at TP75/76/90 before qualification.
Existing v0.2 bench firmware keeps camera OFF and does not operate this UART. Full system incomplete.

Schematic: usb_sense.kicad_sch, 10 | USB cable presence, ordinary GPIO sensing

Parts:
R9: 6.2k 1%; R0402; Manufacturer Part 0402WGF6201TCE; LCSC C25915
R110: 10k 0.1%; R_0603_1608Metric; Manufacturer Part RT0603BRD0710KL; LCSC C95204
TP92: VBUS_SENSE; M3_TestPad_1.5

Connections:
GND: R110.2; also elsewhere on the board
VBUS: R9.1; also elsewhere on the board
VBUS_SENSE: R9.2, R110.1, TP92.1; also elsewhere on the board

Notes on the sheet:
10 | USB cable presence, ordinary GPIO sensing
PD15 / U1 pin62 is a regular FT_h GPIO input. PA9 remains NC. D+/D- are unchanged.
R9=6.2k 1%, R110=10k 0.1%; TP92 measures their junction. No internal pull-up/down.
Input range and tolerance calculation uses DS12110 Rev11, Tables14/112 and50/147.
Use software attach/detach from PD15. Do NOT enable native PA9 VBUS sensing (VBDEN).
USB 48MHz source, descriptors, suspend current and actual enumeration remain unqualified.
VBUS decay depends on C28/C83/C86 and mux/switch leakage. RC estimates are conditional.
Measure reset/unpowered input, USB plug/unplug, discharge and hot leakage before acceptance.
Old v0.2-v0.5 firmware is bound to previous board hashes, not to this new candidate.

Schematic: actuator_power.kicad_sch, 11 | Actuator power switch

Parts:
C120: 2.2uF; C0603; LCSC C23630
C121: 470uF 25V; CAP-SMD_BD8.0-L8.3-W8.3-LS9.0-FD_H10.5; Manufacturer Part MA25V470M8x10; LCSC C46550466
C122: 10nF; C0603; LCSC C57112
Q120, Q121: AON6403; PDFN-8_L5.6-W5.2-P1.27-LS6.1-BL; Manufacturer Part AON6403; LCSC C2760089
Q122: AO3400A; SOT-23-3_L2.9-W1.3-P1.90-LS2.4-BR; Manufacturer Part AO3400A; LCSC C20917
R120, R122, R123: 100k; R0402; LCSC C25741
R121, R124: 10k; R0402; LCSC C25744
R125: 4.7k; R0402; LCSC C25900
TP120: RAW_ACT; M3_TestPad_1.5
TP121: ACT_GATE; M3_TestPad_1.5

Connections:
ACT_DRV: Q122.3 (D), R121.2
ACT_EN: Q122.1 (G), R122.2, R123.1
ACT_FET_S: C120.1, Q120.1 (S), Q120.2 (S), Q120.3 (S), Q121.1 (S), Q121.2 (S), Q121.3 (S), R120.1
ACT_GATE: C120.2, Q120.4 (G), Q121.4 (G), R120.2, R121.1, TP121.1
BAT_IN: Q120.5 (D), Q120.6 (D), Q120.7 (D), Q120.8 (D), Q120.9 (D); also elsewhere on the board
GND: C121.2, C122.2, Q122.2 (S), R123.2, R125.2; also elsewhere on the board
RAW_ACT: C121.1, Q121.5 (D), Q121.6 (D), Q121.7 (D), Q121.8 (D), Q121.9 (D), R124.1, TP120.1; also elsewhere on the board
RAW_ACT_SENSE: C122.1, R124.2, R125.1; also elsewhere on the board
RAW_PROTECTED: R122.1; also elsewhere on the board

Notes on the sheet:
11 | Actuator power switch
Second, high-current battery path for servos and pyro. U9 (sheet 07) is NOT sized for actuator current.
Q120/Q121 AON6403 back-to-back: load switch + reverse-battery block + no back-feed from RAW_ACT.
Q122 turns the pair on only while RAW_PROTECTED is up, i.e. it follows the single J1.3-J1.4 switch and U9 fault latch.
USB alone: RAW_PROTECTED = 0, so RAW_ACT, the servo header and the ARM terminal are dead.
C120 is gate-SOURCE (P0-4): a shorted C120 fails OFF. ~150 ms ride-through of contact bounce (inference, X5R bias).
R124/R125 10k/4.7k -> PB0: RAW_ACT sense AND bleed (tau ~7 s with C121). Mandatory external 15 A ATO fuse in battery lead.

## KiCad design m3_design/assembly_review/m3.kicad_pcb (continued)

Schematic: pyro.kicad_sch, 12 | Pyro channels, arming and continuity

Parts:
C126, C138: 220nF 25V X7R; C0603; Manufacturer Part CL10B224KA8NNNC; LCSC C21120
C127, C129, C139, C141: 10nF; C0603; LCSC C57112
C128, C140: 100nF 50V X7R 10%; C_0603_1608Metric; Manufacturer Part CL10B104KB8NNNC; LCSC C1591
D120: BAT54A; SOT-23-3_L2.9-W1.3-P1.90-LS2.4-BR; Manufacturer Part BAT54A; LCSC C8591
J120: ARM: RAW / BUS2 / BUS1 / RAW; M3_DB128V_4P; LCSC C2915641
J121: E1- / E1+ / E2+ / E2-; M3_DB128V_4P; LCSC C2915641
Q124, Q125: AON7524; M3_AON7524_DFN3x3A; Manufacturer Part AON7524; LCSC C431195
R126, R138: 220R; R0805; LCSC C17557
R127, R130, R133, R139, R142, R145: 1k; R0402; LCSC C11702
R128, R129, R131, R132, R140, R141, R143, R144: 10k; R0402; LCSC C25744
R134, R135: 2R 1% 2W pulse; R2512; Manufacturer Part CRM2512-FX-2R00ELF; LCSC C3013496
TP122: PYRO1_GATE; M3_TestPad_1.5
TP123: PYRO2_GATE; M3_TestPad_1.5
TP124: GND; M3_TestPad_1.5

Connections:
3V3: D120.3 (A); also elsewhere on the board
ARM1_SENSE: C129.1, R132.2, R133.1; also elsewhere on the board
ARM2_SENSE: C141.1, R144.2, R145.1; also elsewhere on the board
GND: C126.2, C127.2, C128.2, C129.2, C138.2, C139.2, C140.2, C141.2, Q124.1 (S), Q124.2 (S), Q124.3 (S), Q125.1 (S), Q125.2 (S), Q125.3 (S), R127.2, R128.2, R130.2, R133.2, R139.2, R140.2, R142.2, R145.2, TP124.1; also elsewhere on the board
PYRO1_BUS: J120.3, R132.1, R134.2
PYRO1_COLD: D120.1 (K1), R131.2
PYRO1_CONT: C127.1, R129.2, R130.1; also elsewhere on the board
PYRO1_GATE: C126.1, Q124.4 (G), R126.2, R128.1, TP122.1
PYRO1_GATE_N: R126.1, R127.1; also elsewhere on the board
PYRO1_IGN: J121.2, R134.1
PYRO1_OUT: C128.1, J121.1, Q124.5 (D), R129.1, R131.1
PYRO2_BUS: J120.2, R135.2, R144.1
PYRO2_COLD: D120.2 (K2), R143.2
PYRO2_CONT: C139.1, R141.2, R142.1; also elsewhere on the board
PYRO2_GATE: C138.1, Q125.4 (G), R138.2, R140.1, TP123.1
PYRO2_GATE_N: R138.1, R139.1; also elsewhere on the board
PYRO2_IGN: J121.3, R135.1
PYRO2_OUT: C140.1, J121.4, Q125.5 (D), R141.1, R143.1
RAW_ACT: J120.1, J120.4; also elsewhere on the board

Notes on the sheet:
R134/R135: 2 ohm 2 W pulse-rated (Bourns CRM2512, 90 W for 10 ms). Limit a shorted igniter to ~4 A so BAT_IN, the MCU and the other channel survive (m3_design/sim_r2/FINDINGS.md 1). Firmware fire pulse <= 20 ms.
12 | Pyro channels, arming and continuity
Two independent channels (FMEA H-5). ARM plug = 4-wire, 2-fuse link: J120.4->F1 5A FAST->J120.3 (BUS1), J120.1->F2 5A FAST->J120.2 (BUS2).
With the plug out NOTHING connects RAW_ACT to PYRO1_BUS or PYRO2_BUS (AGENTS.md safety rule 1). No test point on BUS/OUT.
Igniter 1 across J121.1-2, igniter 2 across J121.3-4. Both terminal pin orders are reversal-symmetric.
Gate: MCU -> 220R -> gate; 1k pull-down on MCU side; 10k + 220nF gate-source (P0-1/P0-2). Off in reset/unpowered.
PE3 (pin 2) and PE6 (pin 5) are sentinels with no net: firmware drives them low. Never enable TRACE on PE2-PE6.
CONT = 10k/1k from drain (open detector only, CIRCUIT_REVIEW 2.9). ARMn_SENSE = 10k/1k from each fused bus.
D120 + 47k: cold pull-up of both drains (FMEA H-1) for plug-out FET-short detection. In flight: log only, never veto (F-10).

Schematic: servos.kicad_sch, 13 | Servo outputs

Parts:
C150, C151: 22uF; C0805; LCSC C45783
D121: SRV05-4; SOT-23-6_L2.9-W1.6-P0.95-LS2.8-BL; Manufacturer Part SRV05-4.TCT; LCSC C13612
J122: SERVO 3x4; HDR-TH_12P-P2.54-V-M-R3-C4-S2.54; LCSC C32713291
R150, R151, R152, R153: 1k 0805; R0805; Manufacturer Part 0805W8F1001T5E; LCSC C17513
R154, R155, R156, R157: 10k; R0402; LCSC C25744

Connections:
3V3: D121.5 (VCC); also elsewhere on the board
GND: C150.2, C151.2, D121.2 (GND), J122.3, J122.6, J122.9, J122.12, R154.2, R155.2, R156.2, R157.2; also elsewhere on the board
RAW_ACT: C150.1, C151.1, J122.2, J122.5, J122.8, J122.11; also elsewhere on the board
SERVO1_MCU: D121.1 (IO1), R150.1, R154.1; also elsewhere on the board
SERVO1_OUT: J122.1, R150.2
SERVO2_MCU: D121.3 (IO2), R151.1, R155.1; also elsewhere on the board
SERVO2_OUT: J122.4, R151.2
SERVO3_MCU: D121.4 (IO3), R152.1, R156.1; also elsewhere on the board
SERVO3_OUT: J122.7, R152.2
SERVO4_MCU: D121.6 (IO4), R153.1, R157.1; also elsewhere on the board
SERVO4_OUT: J122.10, R153.2

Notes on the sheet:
13 | Servo outputs
J122 column-major: 1/4/7/10 = SIGNAL 1-4, 2/5/8/11 = RAW_ACT (+), 3/6/9/12 = GND. HV servos only, stall <= 3 A per pin.
Order from the MCU: 10k pull-down and SRV05-4 clamp on the MCU side, then 1.0k 0805 series (P0-5), then the header.
PA0-PA3 = TIM5_CH1-4 (AF2). PUPDR = 00, OSPEEDR = 00, drive low at boot. TIM2 never gets a channel.
Quiet the servos (unloaded centre) before a pyro fire (P1-8). Two zip-tie holes straddle J122.

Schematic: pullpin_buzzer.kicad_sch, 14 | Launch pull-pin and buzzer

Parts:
C160: 100nF; C0402; LCSC C1525
D122: BAT54S; SOT-23-3_L2.9-W1.3-P1.90-LS2.4-BR; Manufacturer Part BAT54S,215; LCSC C47546
D123: 1N5819WS; SOD-323_L1.8-W1.3-LS2.5-RD; Manufacturer Part 1N5819WS; LCSC C191023
J123: PULL-PIN 1x2; M3_PULLPIN_1x2; Manufacturer Part PZ254V-11-02P; LCSC C492401
LS120: MLT-8530; BUZ-SMD_4P-L8.5-W8.5-P8.50-BR; Manufacturer Part MLT-8530; LCSC C94599
Q123: AO3400A; SOT-23-3_L2.9-W1.3-P1.90-LS2.4-BR; Manufacturer Part AO3400A; LCSC C20917
R160: 1k; R0402; LCSC C11702
R161, R163: 10k; R0402; LCSC C25744
R162: 220R; R0805; LCSC C17557

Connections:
3V3: D122.2 (K2), D123.1 (K), LS120.1 (+), R161.1; also elsewhere on the board
BUZZ_DRV: R162.1; also elsewhere on the board
BUZZ_G: Q123.1 (G), R162.2, R163.1
BUZZ_OUT: D123.2 (A), LS120.2 (-), Q123.3 (D)
GND: C160.2, D122.1 (A1), J123.2, Q123.2 (S), R163.2; also elsewhere on the board
PULLPIN: C160.1, D122.3 (K1A2), R160.2, R161.2; also elsewhere on the board
PULLPIN_EXT: J123.1, R160.1

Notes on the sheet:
14 | Launch pull-pin and buzzer
Pull-pin: PC14 (pin 8) reads LOW with the pin inserted, HIGH when pulled. Advisory only (FMEA F-7); ignored after launch.
D122 BAT54S clamps PULLPIN to 3V3/GND: an 8.4 V chafe would otherwise put 7.94 V on the pin (FMEA H-10).
LS120 MLT-8530: pad 1 = + lead, pad 2 = - lead, pads 3/4 = dummy (Huaneng spec 5.2). Closes CIRCUIT_REVIEW 3.4.
BUZZ_DRV = PA5 (pin 29), moved off PE6 (P1-10). 2.7 kHz 50 % duty, software toggle or TIM8_CH1N (AF3, inference). Never TIM2.


Board: 4 copper layers, 46.0 x 238.0 mm, 208 parts (0 on the bottom side), 112 nets.

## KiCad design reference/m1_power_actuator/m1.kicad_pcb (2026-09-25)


Board: 4 copper layers, 46.0 x 66.0 mm, 36 parts (0 on the bottom side), 27 nets.

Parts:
C1: 470uF/25V; CAP-SMD_BD8.0-L8.3-W8.3-LS9.0-FD_H10.5
C2, C3: 22uF; C0805
C35, C36: 10nF; C0603
D1: SMBJ12CA; SMB_L4.6-W3.6-LS5.3-BI
J1: BAT+/BAT-/SW/SW; CONN-TH_4P-P5.08_DIBO_DB128V-5.08
J4: ARM/PYRO; CONN-TH_6P-P5.08_DIBO_DB128V-5.08
J5: SERVO 3x4; HDR-TH_12P-P2.54-V-M-R3-C4-S2.54
J10: J-IF1 power+drive; CONN-TH_12P-P2.00_S12B-PH-K-S-LF-SN
J10T: J-IF1 solder/test row; HDR-TH_12P-P2.54-V-M-1x12
J11: J-IF2 sense+ID; CONN-TH_9P-P2.00_S9B-PH-K-S-LF-SN
J11T: J-IF2 solder/test row; HDR-TH_9P-P2.54-V-M-1x9
Q1, Q2: AON6403; PDFN-8_L5.6-W5.2-P1.27-LS6.1-BL
Q3, Q4: AO3400A; SOT-23-3_L2.9-W1.3-P1.90-LS2.4-BR
R1, R44: 100k; R0402
R2, R14, R18, R22, R40, R41, R42, R43: 10k; R0402
R17, R21: 1k; R0402
R24, R25, R26, R27: 220R; R0805
R50, R51: 0R; R0805
R52: DNP; R0402

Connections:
ARM_SENSE: J11.2, J11T.2, R14.2
BAT+: D1.1, J1.1, Q1.5, Q1.6, Q1.7, Q1.8, Q1.9
FET_S: Q1.1, Q1.2, Q1.3, Q2.1, Q2.2, Q2.3, R1.2
GATE_DRV: R1.1, R2.1, R51.1, R52.1
GATE_SW: Q1.4, Q2.4, R51.2
GND: C1.2, C2.2, C3.2, C35.2, C36.2, D1.2, J1.2, J5.3, J5.6, J5.9, J5.12, J10.1, J10.3, J10.5, J10.10, J10T.1, J10T.3, J10T.5, J10T.10, J11.1, J11.7, J11.9, J11T.1, J11T.7, J11T.9, Q3.2, Q4.2, R17.2, R21.2, R40.2, R41.2, R42.2, R43.2
ID0: J11.6, J11T.6
ID2: J11.8, J11T.8
PYRO1_CONT: J11.3, J11T.3, R18.2
PYRO1_GATE: C35.1, J10.2, J10T.2, Q3.1, R17.1
PYRO1_OUT: J4.4, Q3.3, R18.1
PYRO2_CONT: J11.4, J11T.4, R22.2
PYRO2_GATE: C36.1, J10.4, J10T.4, Q4.1, R21.1
PYRO2_OUT: J4.6, Q4.3, R22.1
PYRO_BUS: J4.2, J4.3, J4.5, R14.1
RAW: C1.1, C2.1, C3.1, J4.1, J5.2, J5.5, J5.8, J5.11, Q2.5, Q2.6, Q2.7, Q2.8, Q2.9, R44.1, R50.1
RAW_IF: J10.11, J10.12, J10T.11, J10T.12, R50.2
RAW_SENSE_PWR: J11.5, J11T.5, R44.2
SERVO1_MCU: J10.6, J10T.6, R24.1, R40.1
SERVO1_OUT: J5.1, R24.2
SERVO2_MCU: J10.7, J10T.7, R25.1, R41.1
SERVO2_OUT: J5.4, R25.2
SERVO3_MCU: J10.8, J10T.8, R26.1, R42.1
SERVO3_OUT: J5.7, R26.2
SERVO4_MCU: J10.9, J10T.9, R27.1, R43.1
SERVO4_OUT: J5.10, R27.2
SW_TERM: J1.3, J1.4, R2.2, R52.2

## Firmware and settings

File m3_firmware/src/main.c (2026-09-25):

/* M3-PWR-R3 BENCH measurements. Slow software SPI/I2C exposes wiring responses.
 * ADC voltage / MS5611 pressure samples have raw evidence and timestamps.
 * Optional v4 hardware SPI adds decimated IMU raw observations; v5 adds an
 * explicitly selected append-only logger or read-only inspection. v6 adds a USB
 * CDC readout. Physical USB, sensor accuracy and watchdog behavior are NOT
 * qualified. No actuation/flight-state logic.
 */
#include "stm32h7xx_hal.h"
#include "checks.h"
#include "voltage.h"
#include "generated.h"
#ifdef M3_POWER_STATUS
#include "power_status.h"
_Static_assert(W_POWER_FLAGS==153 && W_POWER_MAX_GAP_MS==159,"Power result placement");
#endif
#ifdef M3_GNSS
#include "gnss.h"
_Static_assert(W_GNSS_STATE==184 && W_GNSS_VERSION==230,"GNSS result placement");
#endif
#ifdef M3_USB
#include "usb.h"
#include "usb_wire.h"
_Static_assert(W_USB_STATE==160 && W_USB_RESERVED==183,"USB result placement");
#endif
#ifdef M3_STORAGE
#include "storage.h"
_Static_assert(W_STORE_MODE==128 && W_STORE_RESERVED==153,"Storage record placement");
#endif
#ifdef M3_IMU_SAMPLES
#include "imu.h"
_Static_assert(W_IMU_SAMPLE_STATUS==112 && W_IMU_RAW==122 && W_IMU_BUS_HZ==126, "IMU record placement");
#endif
#ifdef M3_CAMERA_UART
#include "camera.h"
_Static_assert(W_CAMERA_STATUS == 82 && W_CAMERA_PACKET == 110, "Camera result placement");
#endif
#include <string.h>

_Static_assert(sizeof(uint32_t) == 4, "Mailbox requires 32-bit words");
_Static_assert(D1_AXISRAM_BASE == MB_ADDRESS, "Wrong SRAM address");
#ifdef M3_HOST_TEST
__attribute__((aligned(32), used))
#else
__attribute__((section(".bench_mailbox"), aligned(32), used))
#endif
volatile uint32_t bench_mailbox[MB_BYTES / 4];
static uint32_t frame[MB_BYTES / 4];
static uint32_t seq;

static void interfaces(void){
#ifdef M3_GNSS
    BenchGNSS gnss;bench_gnss_status(&gnss);memcpy(&frame[W_GNSS_STATE],&gnss,sizeof(gnss));
#endif
#ifdef M3_USB
    BenchUSB usb;bench_usb_status(&usb);memcpy(&frame[W_USB_STATE],&usb,sizeof(usb));
#endif
#ifdef M3_POWER_STATUS
    /* After the legacy storage copy, which still zeroes reserved words153..155. */
    BenchPowerStatus power;bench_power_status(&power);memcpy(&frame[W_POWER_FLAGS],&power,sizeof(power));
#endif
}
static void publish(void) {
    interfaces();
    frame[W_UPTIME_MS] = HAL_GetTick();
    frame[W_SEQUENCE] = 0;
    frame[W_CRC32] = bench_crc32((const uint8_t *)frame, MB_BYTES - 4);
    bench_mailbox[W_SEQUENCE] = ++seq; /* odd: an update is in progress */
    __DMB();
    for (unsigned i = 0; i < MB_BYTES / 4; ++i)
        if (i != W_SEQUENCE) bench_mailbox[i] = frame[i];
    __DMB();
    bench_mailbox[W_SEQUENCE] = ++seq; /* even: complete committed snapshot */
    __DSB();
}
#ifdef M3_STORAGE
void bench_storage_progress(const BenchStorage *r) {
    memcpy(&frame[W_STORE_MODE],r,sizeof(*r));publish();
#ifdef M3_USB
    bench_usb_task();
#endif
}
#endif
#ifdef M3_USB
unsigned bench_usb_snapshot(void *ctx,uint8_t *out,uint32_t address,uint32_t n){
    (void)ctx;
    if(address || n!=MB_BYTES)return USB_REPLY_BAD_REQUEST;
    uint32_t first=bench_mailbox[W_SEQUENCE];
    if(first&1U)return USB_REPLY_BUSY;
    __DMB();
    for(unsigned i=0;i<MB_BYTES;i++)out[i]=((const volatile uint8_t *)bench_mailbox)[i];
    __DMB();
    return first==bench_mailbox[W_SEQUENCE]?USB_REPLY_OK:USB_REPLY_BUSY;
}
#endif

void SysTick_Handler(void) {
    HAL_IncTick();
#ifdef M3_POWER_STATUS
    bench_power_tick();
#endif
}
/* Vendor Reset_Handler calls newlib's initializer; no constructors/CRT hooks. */
void _init(void) {}

void assert_failed(uint8_t *file, uint32_t line) {
    (void)file;
    frame[W_STATE] = STATE_FATAL;
    frame[W_BUS_ERROR] = 0x80000000U | line;
    publish();
    for (;;) { __NOP(); }
}

typedef struct { GPIO_TypeDef *port; uint16_t pin; } Pin;
static const Pin imu_sck = {GPIOB, GPIO_PIN_3};
static const Pin imu_miso = {GPIOB, GPIO_PIN_4};
static const Pin imu_mosi = {GPIOB, GPIO_PIN_5};
static const Pin imu_cs = {GPIOB, GPIO_PIN_7};
static const Pin flash_sck = {GPIOB, GPIO_PIN_2};
static const Pin flash_miso = {GPIOD, GPIO_PIN_12};
static const Pin flash_mosi = {GPIOD, GPIO_PIN_11};
static const Pin flash_cs = {GPIOB, GPIO_PIN_6};
static const Pin scl = {GPIOB, GPIO_PIN_8};
static const Pin sda = {GPIOB, GPIO_PIN_9};

static void set(Pin p, int high) { HAL_GPIO_WritePin(p.port, p.pin, high ? GPIO_PIN_SET : GPIO_PIN_RESET); }
static int get(Pin p) { return HAL_GPIO_ReadPin(p.port, p.pin) == GPIO_PIN_SET; }
static void half(void) { HAL_Delay(1); } /* deliberately <=500Hz, not throughput evidence */
static void configure(Pin p, uint32_t mode, int initial) {
    GPIO_InitTypeDef g = {0};
    set(p, initial); /* output latch first to avoid selecting a chip prematurely */
    g.Pin = p.pin; g.Mode = mode; g.Pull = GPIO_NOPULL; g.Speed = GPIO_SPEED_FREQ_LOW;
    HAL_GPIO_Init(p.port, &g);
}

static void setup_gpio(void) {
    __HAL_RCC_GPIOB_CLK_ENABLE(); __HAL_RCC_GPIOD_CLK_ENABLE(); __HAL_RCC_GPIOE_CLK_ENABLE();
#ifdef M3_CAMERA_UART
    bench_camera_safe_gpio(); /* PC13 output latch low before enabling output mode */
#else
    configure((Pin){GPIOD, GPIO_PIN_3}, GPIO_MODE_OUTPUT_PP, 0); /* camera stays disabled */
#endif
    configure((Pin){GPIOE, GPIO_PIN_3}, GPIO_MODE_OUTPUT_PP, 0);
    configure((Pin){GPIOE, GPIO_PIN_7}, GPIO_MODE_OUTPUT_PP, 0);
    configure(imu_cs, GPIO_MODE_OUTPUT_PP, 1);
    configure(flash_cs, GPIO_MODE_OUTPUT_PP, 1);
    configure(imu_sck, GPIO_MODE_OUTPUT_PP, 0);
    configure(flash_sck, GPIO_MODE_OUTPUT_PP, 0);
    configure(imu_mosi, GPIO_MODE_OUTPUT_PP, 0);
    configure(flash_mosi, GPIO_MODE_OUTPUT_PP, 0);
    configure(imu_miso, GPIO_MODE_INPUT, 0);
    configure(flash_miso, GPIO_MODE_INPUT, 0);
    configure((Pin){GPIOE, GPIO_PIN_2}, GPIO_MODE_OUTPUT_PP, 1); /* flash /WP */
    configure((Pin){GPIOD, GPIO_PIN_13}, GPIO_MODE_OUTPUT_PP, 1); /* flash /HOLD */
    configure(scl, GPIO_MODE_OUTPUT_OD, 1);
    configure(sda, GPIO_MODE_OUTPUT_OD, 1);
}

static uint8_t spi_byte(Pin clock, Pin dout, Pin din, uint8_t tx) {
    uint8_t rx = 0;
    for (unsigned i = 0; i < 8; ++i) {
        set(dout, (tx & 0x80U) != 0); tx <<= 1;
        half(); set(clock, 1); half();
        rx = (uint8_t)((rx << 1) | (unsigned)get(din));
        set(clock, 0);
    }
    return rx;
}

static void test_imu(void) {
    frame[W_IMU_STATUS] = STATUS_RUNNING; frame[W_STAGE] = 2; publish();
    set(imu_cs, 0); half();
    (void)spi_byte(imu_sck, imu_mosi, imu_miso, 0x80U | 0x72U);
    uint8_t id = spi_byte(imu_sck, imu_mosi, imu_miso, 0);
    half(); set(imu_cs, 1);
    frame[W_IMU_ID] = id;
    frame[W_IMU_STATUS] = id == 0xe9 ? STATUS_PASS : STATUS_FAIL;
    publish();
}

static void test_flash(void) {
    frame[W_FLASH_STATUS] = STATUS_RUNNING; frame[W_STAGE] = 4; publish();
    set(flash_cs, 0); half();
    (void)spi_byte(flash_sck, flash_mosi, flash_miso, 0x9f);
    uint32_t id = 0;
    for (unsigned i = 0; i < 3; ++i)
        id = (id << 8) | spi_byte(flash_sck, flash_mosi, flash_miso, 0);
    half(); set(flash_cs, 1);
    frame[W_FLASH_ID] = id;
    frame[W_FLASH_STATUS] = id == 0xef4018 ? STATUS_PASS : STATUS_FAIL;
    publish();
}

/* Software I2C: use actual line readback, external pull-ups and bounded
 * stretching. Never drive a bus high or scan unrelated devices. One documented
 * MS5611 power-on reset precedes PROM reads; no repeated recovery/reset loop.
 */
static int scl_high(void) {
    set(scl, 1);
    uint32_t start = HAL_GetTick();
    while (!get(scl)) {
        if ((uint32_t)(HAL_GetTick() - start) >= 5) {
            frame[W_BUS_ERROR] = 1; return 0;
        }
    }
    half(); return 1;
}
static int start(void) {
    set(sda, 1);
    if (!scl_high()) return 0;
    if (!get(sda)) { frame[W_BUS_ERROR] = 2; return 0; }
    set(sda, 0); half(); set(scl, 0); half(); return 1;
}
static int stop(void) {
    set(scl, 0); set(sda, 0); half();
    if (!scl_high()) { set(sda, 1); return 0; }
    set(sda, 1); half();
    if (!get(sda)) { frame[W_BUS_ERROR] = 2; return 0; }
    return 1;
}
static int send(uint8_t v) {
    for (unsigned i = 0; i < 8; ++i) {
        set(sda, (v & 0x80U) != 0); v <<= 1; half();
        if (!scl_high()) return 0;
        set(scl, 0); half();
    }
    set(sda, 1); half();
    if (!scl_high()) return 0;
    int ack = !get(sda); set(scl, 0); half();
    if (!ack) frame[W_BUS_ERROR] = 3;
    return ack;
}
static int receive(uint8_t *out, int last) {
    uint8_t v = 0; set(sda, 1);
    for (unsigned i = 0; i < 8; ++i) {
        half(); if (!scl_high()) return 0;
        v = (uint8_t)((v << 1) | (unsigned)get(sda)); set(scl, 0); half();
    }
    set(sda, last); half(); if (!scl_high()) return 0;
    set(scl, 0); set(sda, 1); half(); *out = v; return 1;
}
static int read_prom(unsigned word, uint16_t *out) {
    uint8_t hi = 0, lo = 0;
    /* TE specifies separate command + STOP, followed by read + STOP. */
    int ok = start() && send(0xee) && send((uint8_t)(0xa0U + 2U * word));
    int stopped = stop();
    if (!ok || !stopped) return 0;
    ok = start() && send(0xef) && receive(&hi, 0) && receive(&lo, 1);
    stopped = stop();
    if (!ok || !stopped) return 0;
    *out = (uint16_t)((hi << 8) | lo); return 1;
}
static void test_baro(void) {
    uint16_t prom[8] = {0};
    frame[W_BARO_STATUS] = STATUS_RUNNING; frame[W_STAGE] = 3;
    frame[W_BARO_ADDRESS] = 0x77; publish(); /* CSB=0 => complemented address bit=1 */
    /* TE MS5611 datasheet requires this once after power-on, then 2.8ms reload. */
    int reset_ok = start() && send(0xee) && send(0x1e);
    int stopped = stop();
    if (!reset_ok || !stopped) {
        frame[W_BARO_STATUS] = STATUS_FAIL; publish(); return;
    }
    HAL_Delay(5);
    for (unsigned i = 0; i < 8; ++i) {
        if (!read_prom(i, &prom[i])) {
            frame[W_BARO_STATUS] = STATUS_FAIL; publish(); return;
        }
        frame[W_BARO_PROM + i] = prom[i];
    }
    frame[W_BARO_CRC_CALC] = bench_prom_crc4(prom);
    frame[W_BARO_CRC_STORED] = prom[7] & 15U;
    int ok = bench_prom_nonempty(prom) && frame[W_BARO_CRC_CALC] == frame[W_BARO_CRC_STORED];
    if (!ok) frame[W_BUS_ERROR] = bench_prom_nonempty(prom) ? 4 : 5;
    frame[W_BARO_STATUS] = ok ? STATUS_PASS : STATUS_FAIL; publish();
}

static int baro_conversion(uint8_t command, uint32_t *raw, uint32_t *at) {
    uint8_t hi = 0, mid = 0, lo = 0;
    int ok = start() && send(0xee) && send(command);
    int stopped = stop();
    if (!ok || !stopped) return 0;
    HAL_Delay(11); /* OSR4096 maximum 9.04ms; includes millisecond quantization */
    ok = start() && send(0xee) && send(0x00); /* ADC-read command then STOP */
    stopped = stop();
    if (!ok || !stopped) return 0;
    ok = start() && send(0xef) && receive(&hi, 0) && receive(&mid, 0) && receive(&lo, 1);
    stopped = stop();
    if (!ok || !stopped) return 0;
    *raw = ((uint32_t)hi << 16) | ((uint32_t)mid << 8) | lo;
    *at = HAL_GetTick(); /* read-completed timestamp, not an exact conversion edge */
    return 1;
}

static void sample_baro(void) {
    uint16_t prom[8];
    uint32_t d1 = 0, d2 = 0, t1 = 0, t2 = 0;
    int32_t pressure = 0, temp = 0;
    frame[W_BARO_SAMPLE_STATUS] = STATUS_FAIL;
    frame[W_BARO_SAMPLE_ERROR] = 10;
    if (frame[W_BARO_STATUS] != STATUS_PASS) return;
    for (unsigned i = 0; i < 8; ++i) prom[i] = (uint16_t)frame[W_BARO_PROM + i];
    if (!bench_prom_nonempty(prom) || bench_prom_crc4(prom) != (prom[7] & 15U)) return;
    uint32_t startup_error = frame[W_BUS_ERROR]; frame[W_BUS_ERROR] = 0;
    int ok = baro_conversion(0x48, &d1, &t1);
    if (ok) frame[W_BARO_VALID_MASK] |= 1;
    if (ok) {
        ok = baro_conversion(0x58, &d2, &t2);
        if (ok) frame[W_BARO_VALID_MASK] |= 2;
    }
    frame[W_BARO_D1] = d1; frame[W_BARO_D2] = d2;
    frame[W_BARO_D1_MS] = t1; frame[W_BARO_D2_MS] = t2;
    frame[W_BARO_SAMPLE_ERROR] = frame[W_BUS_ERROR]; frame[W_BUS_ERROR] = startup_error;
    if (!ok) return;
    if (!d1 || !d2 || d1 == 0xffffffU || d2 == 0xffffffU) {
        frame[W_BARO_SAMPLE_ERROR] = 11; return;
    }
    ok = bench_ms5611(prom, d1, d2, &pressure, &temp);
    frame[W_PRESSURE_PA] = (uint32_t)pressure; frame[W_TEMP_CENTIC] = (uint32_t)temp;
    if (!ok) { frame[W_BARO_SAMPLE_ERROR] = 12; return; }
    frame[W_BARO_SAMPLE_STATUS] = STATUS_PASS;
}

static void sample_bench(void) {
    BenchADC a;
    frame[W_ACQ_COUNTER]++;
    for (unsigned i = W_ACQ_START_MS; i <= W_ADC_CR; ++i) frame[i] = 0;
    frame[W_ACQ_START_MS] = HAL_GetTick();
    frame[W_ADC_STATUS] = frame[W_BARO_SAMPLE_STATUS] = STATUS_RUNNING;
    /* Keep the last COMPLETE SRAM snapshot readable during acquisition.
     * Commit once below in main; a stalled conversion cannot advance heartbeat.
     */
    bench_adc_sample(&a);
    frame[W_ADC_STATUS] = a.status; frame[W_ADC_ERROR] = a.error;
    frame[W_ADC_HAL_ERROR] = a.hal_error; frame[W_ADC_INIT_ERROR] = a.init_error;
    frame[W_ADC_VALID_MASK] = a.valid; frame[W_ADC_CAL_RAW] = a.cal;
    frame[W_ADC_REF_RAW] = a.ref; frame[W_ADC_VLOGIC_RAW] = a.logic; frame[W_ADC_3V3_RAW] = a.v3;
    frame[W_VDDA_MV] = a.vdda_mv; frame[W_VLOGIC_MV] = a.logic_mv; frame[W_V3V3_MV] = a.v3_mv;
    frame[W_ADC_SAMPLE_MS] = a.sample_ms; frame[W_SYSCFG_PMCR] = a.pmcr;
    frame[W_ADC_CCR] = a.ccr; frame[W_ADC_PCSEL] = a.pcsel;
    frame[W_ADC_CFGR] = a.cfgr; frame[W_ADC_CR] = a.cr;
    sample_baro();
#ifdef M3_IMU_SAMPLES
    BenchIMU imu;
    bench_imu_sample(&imu);
    memcpy(&frame[W_IMU_SAMPLE_STATUS],&imu,sizeof(imu));
#endif
    frame[W_ACQ_FINISHED_MS] = HAL_GetTick();
}

int main(void) {
    uint32_t reset_flags = RCC->RSR;
    SystemCoreClockUpdate(); /* vendor SystemInit leaves HSI, no PLL */
    HAL_Init();
    /* No I/D cache enable: SWD sees committed SRAM rather than dirty cache. */
    setup_gpio();
#ifdef M3_POWER_STATUS
    bench_power_initialize();
#endif
    for (unsigned i = 0; i < MB_BYTES / 4; ++i) bench_mailbox[i] = 0; /* initialize SRAM/ECC */
    frame[W_MAGIC] = MB_MAGIC; frame[W_VERSION] = MB_VERSION; frame[W_LENGTH] = MB_BYTES;
    frame[W_CAPABILITIES] = MB_CAPABILITIES; frame[W_STATE] = STATE_BOOT;
    memcpy(&frame[W_BOARD_SHA], board_sha, 32); memcpy(&frame[W_BUILD_SHA], build_sha, 32);
    frame[W_RESET_FLAGS] = reset_flags; frame[W_DEVICE_ID] = DBGMCU->IDCODE;
    for (unsigned i = 0; i < 3; ++i) frame[W_UID + i] = ((const uint32_t *)UID_BASE)[i];
    frame[W_RCC_CFGR] = RCC->CFGR;
    frame[W_CAM_ENABLE_READBACK] = HAL_GPIO_ReadPin(GPIOD, GPIO_PIN_3);
    publish();
    if (SystemCoreClock != 64000000U || (RCC->CFGR & RCC_CFGR_SWS) != RCC_CFGR_SWS_HSI) {
        frame[W_STATE] = STATE_FATAL; frame[W_BUS_ERROR] = 6; publish();
        for (;;) { __NOP(); }
    }
    HAL_Delay(100); /* comfortably beyond sensor interface power-up delay */
    frame[W_STATE] = STATE_TESTING; frame[W_STAGE] = 1; frame[W_HSE_STATUS] = STATUS_RUNNING; publish();
    RCC_OscInitTypeDef oscillator = {0};
    oscillator.OscillatorType = RCC_OSCILLATORTYPE_HSE;
    oscillator.HSEState = RCC_HSE_ON;
    oscillator.PLL.PLLState = RCC_PLL_NONE;
    HAL_StatusTypeDef result = HAL_RCC_OscConfig(&oscillator);
    frame[W_HSE_CR] = RCC->CR;
    frame[W_HSE_STATUS] = result == HAL_OK && (RCC->CR & RCC_CR_HSERDY) ? STATUS_PASS : STATUS_FAIL;
    /* Never switch SYSCLK to the tested oscillator. USB alone retains HSE
     * and uses an independent PLL3; older build modes keep their old behavior. */
#ifdef M3_USB
    bench_usb_initialize();publish();
#else
    oscillator.HSEState = RCC_HSE_OFF; (void)HAL_RCC_OscConfig(&oscillator); publish();
#endif
    test_imu(); test_baro(); test_flash();
#ifdef M3_CAMERA_UART
    CameraResult camera;
    frame[W_STAGE] = 6; frame[W_CAMERA_STATUS] = M3_CAMERA_QUERY ? STATUS_RUNNING : STATUS_NOT_TESTED;
    frame[W_CAMERA_MODE] = M3_CAMERA_QUERY;
    publish();
    bench_camera_query(M3_CAMERA_QUERY, &camera);
    memcpy(&frame[W_CAMERA_STATUS], &camera, sizeof(camera));
    frame[W_CAM_ENABLE_READBACK] = HAL_GPIO_ReadPin(GPIOD, GPIO_PIN_3);
    publish();
#endif
#ifdef M3_IMU_SAMPLES
    BenchIMU imu;
    frame[W_STAGE]=7; frame[W_IMU_SAMPLE_STATUS]=STATUS_RUNNING; publish();
    bench_imu_initialize(&imu);
    memcpy(&frame[W_IMU_SAMPLE_STATUS],&imu,sizeof(imu)); publish();
#endif
#ifdef M3_STORAGE
    BenchStorage storage;
    uint8_t identity[76];memcpy(identity,board_sha,32);memcpy(identity+32,build_sha,32);
    memcpy(identity+64,&frame[W_UID],12);
    frame[W_STAGE]=8;frame[W_STORE_STATUS]=STORE_SCANNING;frame[W_STORE_MODE]=M3_STORAGE_RECORD;publish();
    bench_storage_begin(M3_STORAGE_RECORD,identity,&storage);
    memcpy(&frame[W_STORE_MODE],&storage,sizeof(storage));publish();
#endif
#ifdef M3_GNSS
    bench_gnss_initialize();publish();
#endif
    frame[W_STATE] = STATE_READY; frame[W_STAGE] = 5; frame[W_TEST_FINISHED_MS] = HAL_GetTick();
    for (;;) {
        uint32_t began = HAL_GetTick();
        sample_bench();
        frame[W_HEARTBEAT]++;
        frame[W_CAM_ENABLE_READBACK] = HAL_GPIO_ReadPin(GPIOD, GPIO_PIN_3);
#ifdef M3_STORAGE
        frame[W_UPTIME_MS]=HAL_GetTick();frame[W_SEQUENCE]=0;
        /* Record the fixed v5 prefix: words0..126 + reserved zero word127.
         * Storage's live counters and v5 CRC are outside this 512-byte payload. */
        frame[127]=0;
#ifdef M3_GNSS
        /* v7 keeps a complete1024-byte snapshot (five pages); GNSS and USB
         * evidence must not silently disappear with the old512-byte prefix.
         * The storage counters describe state BEFORE this append. */
        bench_gnss_task();interfaces();frame[W_UPTIME_MS]=HAL_GetTick();
        frame[W_CRC32]=bench_crc32((const uint8_t *)frame,MB_BYTES-4);
#endif
        bench_storage_append((const uint8_t *)frame,frame[W_ACQ_COUNTER],&storage);
        memcpy(&frame[W_STORE_MODE],&storage,sizeof(storage));
#endif
        publish(); HAL_GPIO_TogglePin(GPIOE, GPIO_PIN_7);
        uint32_t elapsed = HAL_GetTick() - began;
        if (elapsed < 1000U) HAL_Delay(1000U - elapsed); /* nominal <=1 sample/s, no catch-up */
    }
}

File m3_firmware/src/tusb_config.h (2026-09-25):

#ifndef M3_TUSB_CONFIG_H
#define M3_TUSB_CONFIG_H
#define CFG_TUSB_MCU OPT_MCU_STM32H7
#define CFG_TUSB_OS OPT_OS_NONE
#define CFG_TUSB_DEBUG 0
#define CFG_TUSB_RHPORT0_MODE (OPT_MODE_DEVICE | OPT_MODE_FULL_SPEED)
#define CFG_TUD_ENABLED 1
#define CFG_TUH_ENABLED 0
#define CFG_TUD_MAX_SPEED OPT_MODE_FULL_SPEED
#define CFG_TUD_ENDPOINT0_SIZE 64
#define CFG_TUD_CDC 1
#define CFG_TUD_CDC_NOTIFY 1
#define CFG_TUD_MSC 0
#define CFG_TUD_HID 0
#define CFG_TUD_MIDI 0
#define CFG_TUD_VENDOR 0
#define CFG_TUD_DFU 0
#define CFG_TUD_DFU_RUNTIME 0
#define CFG_TUD_CDC_RX_BUFSIZE 512
#define CFG_TUD_CDC_TX_BUFSIZE 512
#define CFG_TUD_CDC_RX_EPSIZE 64
#define CFG_TUD_CDC_TX_EPSIZE 64
#define CFG_TUD_DWC2_DMA_ENABLE 0
#define CFG_TUD_DWC2_SLAVE_ENABLE 1
#define CFG_TUD_MEM_DCACHE_ENABLE 0
#define CFG_TUSB_MEM_ALIGN __attribute__((aligned(4)))
#define CFG_TUD_VBUS_DETECT_HW 0
#define CFG_TUD_TASK_EVENTS_PER_RUN 8
#endif

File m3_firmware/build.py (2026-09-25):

"""Build a bench-only ELF/HEX/BIN and pin the exact PCB + source identities.
Does not download dependencies, run a programmer, or connect to a board.
"""
import hashlib
import argparse
import json
import os
from pathlib import Path
import subprocess
import sys
import xml.etree.ElementTree as ET

HERE = Path(__file__).resolve().parent
ROOT = HERE.parent
OUT = HERE / 'build'
TOOL = HERE/'toolchain/arm-gnu-toolchain-15.2.rel1-darwin-arm64-arm-none-eabi/bin/arm-none-eabi-'


def sha(path):
    return hashlib.sha256(Path(path).read_bytes()).hexdigest()


def require(condition, message):
    if not condition: raise ValueError(message)


def main():
    global OUT
    parser=argparse.ArgumentParser(description=__doc__)
    parser.add_argument('--board',choices=['power','uart','usb','gnss','status','assembly'],default='power')
    parser.add_argument('--camera-query',action='store_true',help='UART/USB board: query camera once at boot, leave power ON')
    parser.add_argument('--imu-samples',action='store_true',help='UART/USB board: raw IMU bench observations')
    parser.add_argument('--storage',choices=['inspect','record'],help='Bench logger; inspect is read-only, record appends without erase')
    args=parser.parse_args()
    modern=args.board in ('uart','usb','gnss','status','assembly')
    usb=args.board in ('usb','gnss','status','assembly')
    gnss=args.board in ('gnss','status','assembly')
    status=args.board in ('status','assembly')
    require(not args.camera_query or modern,'Camera query requires reviewed UART/USB hardware')
    require(not args.imu_samples or modern,'IMU bench acquisition requires a reviewed binding')
    require(not args.storage or (modern and args.imu_samples),'Storage requires UART/USB hardware and --imu-samples')
    require(not usb or (args.storage and args.imu_samples),'USB/GNSS diagnostics include the existing storage and IMU record')
    suffix='_uart' if modern else ''
    protocol_path=HERE/('protocol'+suffix+'.json');pins_path=HERE/('pins'+suffix+'.json')
    if args.imu_samples:protocol_path=HERE/'protocol_imu.json'
    if args.storage:protocol_path=HERE/'protocol_storage.json'
    if args.board=='usb':protocol_path=HERE/'protocol_usb.json';pins_path=HERE/'pins_usb.json'
    if args.board=='gnss':protocol_path=HERE/'protocol_gnss.json';pins_path=HERE/'pins_gnss.json'
    if args.board=='status':protocol_path=HERE/'protocol_status.json';pins_path=HERE/'pins_status.json'
    if args.board=='assembly':protocol_path=HERE/'protocol_assembly.json';pins_path=HERE/'pins_status.json'
    protocol=json.loads(protocol_path.read_text())
    if gnss:
        for relative,digest in protocol['gnss']['source_hashes'].items():
            require(sha(ROOT/relative)==digest,'GNSS primary reference changed: '+relative)
    if status:
        for relative,digest in protocol['power_status']['source_hashes'].items():
            require(sha(ROOT/relative)==digest,'Power status reference changed: '+relative)
    if args.storage:
        for relative,digest in protocol['storage']['source_hashes'].items():
            require(sha(ROOT/relative)==digest,'Storage reference changed: '+relative)
    if args.imu_samples:
        for relative,digest in protocol['imu']['source_hashes'].items():
            require(sha(ROOT/relative)==digest,'IMU source reference changed: '+relative)
    if modern:
        if args.board=='assembly':from assembly_binding import make_binding
        elif args.board=='status':from status_binding import make_binding
        elif args.board=='gnss':from gnss_binding import make_binding
        elif args.board=='usb':from usb_binding import make_binding
        else:from uart_binding import make_binding
        binding=make_binding()
        folder=ROOT/('m3_design/'+args.board+'_review' if usb else 'm3_design/uart_review')
        if args.board=='status':folder=ROOT/'m3_design/power_status_review'
        OUT=HERE/('build_uart_query' if args.camera_query else 'build_uart_idle')
        if args.imu_samples:OUT=HERE/('build_imu_query' if args.camera_query else 'build_imu_idle')
        if args.storage:OUT=HERE/('build_storage_'+args.storage+('_query' if args.camera_query else ''))
        if usb:OUT=HERE/('build_'+args.board+'_'+args.storage+('_query' if args.camera_query else ''))
    else:
        folder=ROOT/'m3_design/power_review'
        binding=json.loads((folder/'diagnostics_binding.json').read_text())
    board=folder/'m3.kicad_pcb'
    require(binding['profile']==protocol['profile'],'Unsupported board profile')
    require(binding['board_sha256'] == sha(board), 'PCB changed; review binding before compiling')
    if modern:require(sha(board)==protocol['board_sha256'],'Revision changed; firmware pin map needs review')
    # Native schematic netlist must agree with every firmware GPIO's pin name.
    tree = ET.parse(folder/'schematic.net.xml')
    names = {n.attrib['pinfunction'].rsplit('_', 1)[0]: net.attrib['name']
             for net in tree.findall('.//nets/net') for n in net.findall('node')
             if n.attrib['ref'] == 'U1'}
    for pin, net in json.loads(pins_path.read_text()).items():
        require(names.get(pin) == net, str((pin, net, names.get(pin))))
    components = {c.attrib['ref']: c.findtext('value') for c in tree.findall('.//components/comp')}
    if args.imu_samples:require(components.get('U4')=='ICM-45686','Unexpected IMU part')
    for ref, expected in {'R60':'100k','R61':'10k','R62':'10k','R63':'10k'}.items():
        require(components.get(ref) == expected, 'ADC divider value changed: ' + ref)
    pin_nets = {(n.attrib['ref'],n.attrib['pin']): net.attrib['name']
                for net in tree.findall('.//nets/net') for n in net.findall('node')}
    if args.storage:
        require(components.get('U3')=='W25Q128JVSIQ','Unreviewed Flash part')
        for pin,net in {'1':'QSPI_NCS','2':'QSPI_IO1','3':'QSPI_IO2','4':'GND',
                        '5':'QSPI_IO0','6':'QSPI_CLK','7':'QSPI_IO3','8':'3V3'}.items():
            require(pin_nets.get(('U3',pin))==net,'Flash pad/net changed: '+pin)
        require(sha(HERE/'research/w25q128jv.pdf')==protocol['storage']['datasheet_sha256'],'Flash primary reference changed')
    if args.imu_samples:
        expected_imu={'1':'SPI1_MISO','2':'GND','3':'GND','4':'IMU_INT1','5':'3V3A',
                      '6':'GND','7':'GND','8':'3V3A','10':'GND','11':'GND','12':'IMU_CS',
                      '13':'SPI1_SCK','14':'SPI1_MOSI'}
        for pin,net in expected_imu.items():require(pin_nets.get(('U4',pin))==net,'IMU pin/pull configuration changed: '+pin)
        require(pin_nets.get(('U4','9'),'').startswith('unconnected-'),'Floating INT2 pull assumption changed')
    for ref, pair in {'R60':('VLOGIC','VLOGIC_SENSE'), 'R61':('VLOGIC_SENSE','GND'),
                      'R62':('3V3','V3V3_SENSE'), 'R63':('V3V3_SENSE','GND')}.items():
        require({pin_nets.get((ref,'1')),pin_nets.get((ref,'2'))} == set(pair),
                'ADC divider topology changed: ' + ref)
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

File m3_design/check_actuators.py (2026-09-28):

#!/usr/bin/env python3
"""Safety contract for the R2 actuator merge, read from the saved PCB (pad nets), not the schematic.

usage: python3 m3_design/check_actuators.py [board.kicad_pcb]      exit 0 = every rule holds

These rules restate AGENTS.md §2 and docs/M3_ACTUATOR_MERGE.md in machine-checkable form. They
qualify the CAD netlist only: no electrical, thermal or physical behaviour is proven here.
"""
import sys
from pathlib import Path
HERE = Path(__file__).resolve().parent
sys.path.insert(0, str(HERE.parent / 'quality_audit'))
from sexpr import read, properties  # noqa: E402


def pad_nets(text):
    pins, vals = {}, {}
    for fp in read(text).children('footprint'):
        ref = properties(fp)['Reference'].items[2].atom
        vals[ref] = properties(fp)['Value'].items[2].atom
        for p in fp.children('pad'):
            num = p.items[1].atom
            if num:
                n = p.children('net')
                pins[f'{ref}.{num}'] = n[0].items[-1].atom if n else None
    return pins, vals


def check(text):
    pin, val = pad_nets(text)
    members = {}
    for p, n in pin.items():
        if n: members.setdefault(n, set()).add(p)
    issues = []
    def req(ok, msg):
        if not ok: issues.append(msg)
    # 1. arming break: each bus touches only its ARM pin, its arm-sense upper arm and its series
    #    resistor; the igniter side of that resistor touches only the igniter terminal
    req(members.get('PYRO1_BUS') == {'J120.3', 'R134.2', 'R132.1'}, 'PYRO1_BUS must be {J120.3, R134.2, R132.1}')
    req(members.get('PYRO2_BUS') == {'J120.2', 'R135.2', 'R144.1'}, 'PYRO2_BUS must be {J120.2, R135.2, R144.1}')
    req(members.get('PYRO1_IGN') == {'J121.2', 'R134.1'}, 'PYRO1_IGN must be {J121.2, R134.1}')
    req(members.get('PYRO2_IGN') == {'J121.3', 'R135.1'}, 'PYRO2_IGN must be {J121.3, R135.1}')
    # 1b. shorted-igniter current limit (sim_r2/FINDINGS.md 1): 2 ohm pulse-rated 2512 per channel
    for r in ('R134', 'R135'):
        req(val.get(r) == '2R 1% 2W pulse', f'{r} must be the 2 ohm 2 W pulse resistor')
    # 1c. cold pull-up strength (sim_r2/FINDINGS.md 2): 10k keeps the plug-out states apart
    for r in ('R131', 'R143'):
        req(val.get(r) == '10k', f'{r} cold pull-up must be 10k')
    req({'J120.1', 'J120.4'} <= members.get('RAW_ACT', set()), 'ARM terminal outer pins must be RAW_ACT')
    req(not ({'J120.2', 'J120.3'} & members.get('RAW_ACT', set())), 'no ARM bus pin may be RAW_ACT')
    # 2. no probe points on bus or igniter nets (DESIGN_ASSURANCE: never place TP on BUS/OUT)
    for n in ('PYRO1_BUS', 'PYRO2_BUS', 'PYRO1_IGN', 'PYRO2_IGN', 'PYRO1_OUT', 'PYRO2_OUT', 'RAW_ACT'):
        tps = sorted(p for p in members.get(n, ()) if p.startswith('TP') and n != 'RAW_ACT')
        req(not tps, f'test point on {n}: {tps}')
    # 3. pyro bus comes after the actuator load switch, never straight from the battery
    req('Q121.5' in members.get('RAW_ACT', set()) and 'Q120.5' in members.get('BAT_IN', set()),
        'RAW_ACT must be the Q121 drain; Q120 drain on BAT_IN')
    req(not (members.get('BAT_IN', set()) & {'J120.1', 'J120.4', 'J121.1', 'J121.2', 'J121.3', 'J121.4'}),
        'no pyro terminal pin on BAT_IN')
    # 4. gate networks: series R, pull-down on the MCU side, gate-source R and C, defined off in reset
    for ch, q, rs, rpd, rgs, cgs, mcu in ((1, 'Q124', 'R126', 'R127', 'R128', 'C126', 'U1.3'),
                                         (2, 'Q125', 'R138', 'R139', 'R140', 'C138', 'U1.4')):
        g, gn = f'PYRO{ch}_GATE', f'PYRO{ch}_GATE_N'
        req(pin.get(f'{q}.4') == g, f'{q} gate on {g}')
        req(pin.get(f'{q}.5') == f'PYRO{ch}_OUT', f'{q} drain on PYRO{ch}_OUT')
        req(all(pin.get(f'{q}.{k}') == 'GND' for k in '123'), f'{q} sources on GND')
        req({pin.get(f'{rs}.1'), pin.get(f'{rs}.2')} == {g, gn}, f'{rs} series between {gn} and {g}')
        req({pin.get(f'{rpd}.1'), pin.get(f'{rpd}.2')} == {gn, 'GND'}, f'{rpd} pull-down on {gn}')
        req({pin.get(f'{rgs}.1'), pin.get(f'{rgs}.2')} == {g, 'GND'}, f'{rgs} gate-source resistor')
        req({pin.get(f'{cgs}.1'), pin.get(f'{cgs}.2')} == {g, 'GND'}, f'{cgs} gate-source capacitor')
        req(members.get(gn) == {mcu, f'{rs}.1', f'{rpd}.1'}, f'{gn} must be only {mcu}, {rs}, {rpd}')
        req(val.get(q) == 'AON7524' and val.get(cgs, '').startswith('220nF'), f'{q}/{cgs} values')
    # 5. sentinel pins beside the pyro gates carry no net (firmware drives them low)
    for p in ('U1.2', 'U1.5'):
        req(pin.get(p) is None or pin.get(p, '').startswith('unconnected-'), f'{p} must stay a no-net sentinel')
    # 6. two independent channels: nothing but the terminals and dividers on the drains
    req(members.get('PYRO1_OUT') == {'J121.1', 'Q124.5', 'R129.1', 'R131.1', 'C128.1'}, 'PYRO1_OUT membership')
    req(members.get('PYRO2_OUT') == {'J121.4', 'Q125.5', 'R141.1', 'R143.1', 'C140.1'}, 'PYRO2_OUT membership')
    # 7. servo chain order: MCU -> pull-down + clamp -> 1k series -> header
    for i, pa in enumerate(('22', '23', '24', '25'), start=1):
        m, o = f'SERVO{i}_MCU', f'SERVO{i}_OUT'
        req(f'U1.{pa}' in members.get(m, set()), f'{m} on U1.{pa}')
        req(members.get(o) == {f'J122.{1 + 3 * (i - 1)}', f'R{149 + i}.2'}, f'{o} only header + series R')
        req(val.get(f'R{149 + i}') == '1k 0805', f'R{149 + i} must be 1k 0805')
    req(all(pin.get(f'J122.{k}') == 'RAW_ACT' for k in (2, 5, 8, 11)), 'servo + row on RAW_ACT')
    req(all(pin.get(f'J122.{k}') == 'GND' for k in (3, 6, 9, 12)), 'servo - row on GND')
    # 8. actuator switch is gated by the logic path (single external switch)
    req({pin.get('R122.1'), pin.get('R122.2')} == {'RAW_PROTECTED', 'ACT_EN'}, 'ACT_EN divider from RAW_PROTECTED')
    req(pin.get('Q122.1') == 'ACT_EN' and pin.get('Q122.3') == 'ACT_DRV', 'Q122 drives the load-switch gate')
    # 9. buzzer pad mapping (Huaneng spec 5.2) and pull-pin clamp
    req(pin.get('LS120.1') == '3V3' and pin.get('LS120.2') == 'BUZZ_OUT', 'LS120 + to 3V3, - to BUZZ_OUT')
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

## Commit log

2026-09-25 M3 single-board flight computer: KiCad project, firmware, diagnostics, design docs
    [battery_entry.kicad_sch, camera_connector.kicad_sch, camera_power.kicad_sch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]
2026-09-26 M3-ASSY-R2: merge servos, dual fused pyro, arming, pull-pin and buzzer
    Adds every remaining hardware function to the single M3 board (46 x 238 mm,
    203 positions / 178 fitted parts, 14 sheets):
    - Actuator power switch: back-to-back AON6403 from the battery input, gated
    by the U9 logic path so the one external switch still controls everything.
    - Single-deploy dual pyro (owner ruling 2026-09-25): two AON7524 channels on
    two independently fused buses (FMEA H-5), separate 4-pos ARM and igniter
    terminals, per-bus arm sense, continuity, cold pull-up (H-1), gate networks
    per MARGIN_PRESCRIPTION P0-1/P0-2, PE3/PE6 sentinels (LED_RED -> PE8).
    - Four servos (1 k series, pull-downs, SRV05-4), c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
    [actuator_power.kicad_sch, camera_uart.kicad_sch, logic_power_path.kicad_sch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]
2026-09-28 R2 actuator-band SPICE suite; rebind R1-only diagnostics to an archived R1 board
    - m3_design/sim_r2: ngspice decks generated from the R2 schematic values
    (actuator switch, pyro fire, fired-into-short with a melting fuse, ARM plug
    insertion Miller case, sense states, servo and pull-pin chafe), datasheet-
    fitted models, RESULTS.md and FINDINGS.md.
    - Finding 1 (open): a shorted igniter on one channel pulls BAT_IN below 5 V
    for 4-60 ms until the 5 A fuse melts, longer than the logic hold-up.
    - The merge of R2 broke 21 diagnostics tests: triage is hash-bound to the R1
    PCB. Archive that board under reference/m3_assy_r1 and bind to it; 173/173
    pass with the pinned requirements.
    Co-Auth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
    [m3.kicad_pcb]
2026-09-28 Limit a shorted igniter to ~4 A: R134/R135 2 ohm pulse resistors, 10k cold pull-ups
    Simulation of R2 as merged showed that firing into a shorted igniter pulled
    BAT_IN below 5 V for 4-20 ms until the 5 A arming fuse melted (MCU reset,
    channel 2 lost) and overstressed the AON7524 at a fresh pack.
    - R134/R135 Bourns CRM2512-FX-2R00ELF (C3013496) in series between each fused
    bus and the igniter terminal (new nets PYRO1_IGN/PYRO2_IGN); arm sense stays
    on the plug side. Placed in line on the bus straps; TP124 moved, four
    references moved to free silkscreen.
    - R131/R143 cold pull-ups 47k -> 10k for plug-out self-test margin.
    - check_actuators.py contract updated (+ negative cases verified by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
    [actuator_power.kicad_sch, battery_entry.kicad_sch, camera_power.kicad_sch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]
2026-09-28 R2 part-by-part datasheet verification; fix every issue found
    All 99 BOM lines / 205 positions checked against manufacturer datasheets
    (pinout, land pattern, polarity, part number, 3D orientation); record in
    docs/R2_VERIFICATION.md.
    Fixes:
    - R134/R135: Bourns CRM2512 recommended land (2.45 x 3.7 mm pads, 7.6 mm),
    moved to keep clearance; generic 2512 land had ~45 % of the pad area.
    - BOOT0 rerouted out from between the MS5611 pads (TE: do not route
    between pads); 0/45/90 segments instead of 0.1 mm staircases.
    - C84 polarity mark on the top side; U12 pin-1 mark.
    - AON7524 3D model rotated 180 deg; L1/L2 model height 3.0 mm.
    - R84 C705743, R9 C25915, R86 80.6k 0.1% C861568 (80k not ordera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
    [battery_entry.kicad_sch, logic_power_path.kicad_sch, m3.kicad_pcb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]
2026-09-28 Make R2 orderable: stocked drop-ins, JLC placement corrections, ordering guide
    - Stock (JLC assembly API): U8 AP63200 -> AP63300WU-7 (same TSOT26 pinout,
    VFB, fsw), L3 -> SRP5030T-6R8M (same body/land, AP63300 Table 1), C77
    100p -> 47p (Table 1), C84 25SVPF330M -> 35SVPK330M (same OS-CON F12).
    Every BOM line now has JLC stock for 5 boards except U6 SAM-M10Q
    (consign / Global Sourcing; DigiKey has stock).
    - tools/jlc_orient.py matches each footprint pad-by-pad to the LCSC/EasyEDA
    footprint of its LCSC code; export_fab.py applies the rotation/offset.
    Without it U7, U8, U10, U11, U12, U13, D121 and LED2 would be rotated.
    - tools/jlc_stock.py: repeatable stock check; fab/stock_check.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
    [camera_power.kicad_sch, diagnostics.kicad_sch, logic_power_path.kicad_sch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]
2026-09-28 Full PCBA: stocked J2/J123 headers, THT parts in the CPL with orientation corrections
    - J2 -> PZ254V-11-06P (C492405), J123 -> PZ254V-11-02P (C492401); JLC cannot
    cut the former 1x40 strip.
    - export_fab.py writes through-hole parts to the CPL (JLC THT assembly) and
    marks them 'THT (JLC THT assembly)'.
    - jlc_corrections.json keyed by LCSC code + footprint (J1 and J9/J120/J121
    share C2915641 with two footprint variants); THT pad data added.
    - ORDERING.md: full PCBA; U6 via JLC Global Sourcing or consignment.
    DRC 0 / unconnected 0 / parity 0 / ERC 0, audit OK; contract OK; tests pass.
    Claude-Session: https://claude.ai/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
    [m3.kicad_pcb, m3_bom_jlc.csv, mcu.kicad_sch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]
2026-09-28 Add CAM_5V sense (R104/R105/C94 -> PB1) so the USB self-test covers the camera regulator
    AUTOTEST_DESIGN's sensing set is already on R2 (VLOGIC, 3V3, RAW_ACT, VBUS,
    arm/continuity with cold pull-up, internal channels, buzzer load step); the
    new camera branch had only a fault flag. CAM_5V x 1k/11k -> PB1 (ADC12_INP5):
    0.477 V at 5.25 V, 1.40 V at the 15.4 V TVS clamp (< TT 4.0 V). Live only
    while the board and the camera branch are powered, so no always-live path
    into an unpowered MCU (AUTOTEST 2.4). Parts reuse existing LCSC codes.
    Routed out from U1's outer side (0/45/90, 4 vias), no fan-out inside the
    LQFP ring. DRC 0 / unconnected 0 / parity 0 / ERC 0, audit OK; tests pass;
    CPL fully ori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
    [diagnostics.kicad_sch, m3.kicad_pcb, m3_bom_jlc.csv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]
2026-11-03 MIT review: README with credits and design-only status, third-party notices
    - README: what it is, demo (board checks + shorted-igniter simulation plot),
    how it works, commands re-run on 2026-11-01, repo layout, honest limits,
    and credits split between Jerry, the AI assistants and the collaborator /
    open-source work.
    - THIRD_PARTY_NOTICES.md: TinyUSB (MIT), STM32 HAL (BSD-3-Clause), CMSIS
    (Apache-2.0), KiCad library models (CC-BY-SA 4.0 with exception),
    EasyEDA/LCSC-derived models, TDK and pyOCD reference copies.
    - docs/images: board render and simulation plot; m3_design/sim_r2/plot_short.py
    redraws the plot from the ngspice output.
    - .gitignore: never commit .env files, keys or l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
2026-11-03 MIT review: per-tool AI credits; drop copied datasheet pages
    - README credits: what Claude Code and Codex each did; Claude Code chose
    the 2 ohm pulse resistors (Jerry approved) and merged PRs #1-#5 on
    Jerry's account.
    - Remove three unreferenced page images copied from maker datasheets
    (m3_design/assembly_review/sources/*_drawing.png); datasheets are
    linked, not stored.
